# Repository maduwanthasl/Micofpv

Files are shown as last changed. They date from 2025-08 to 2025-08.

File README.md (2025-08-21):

# Custom 5" Freestyle FPV Build (Mark4 + DJI O4 Air Unit Pro)

**Type:** 5" freestyle • **FC/ESC:** SpeedyBee F405 V4 + 60A BLS 4-in-1 • **RX:** ExpressLRS 2.4G • **Video:** DJI O4 Air Unit Pro • **Props:** 5×3.3

**Demo video:** [Instagram Reel](https://www.instagram.com/reel/DLZa7YPyZ9yfRRH4GAgoWavU5bKhOaAaTe52I00/?igsh=MXVkb3AwZjJoZG41NA==)  
**Build photo:** [Image](https://github.com/maduwanthasl/Micofpv/blob/main/Images/fpv_image.jpg)

---

Freestyle FPV — Mark4 + O4

## Overview
I built this quad because I’m deeply interested in FPV and wanted a hobby freestyle rig that helps me unwind while delivering durable performance and clean HD video. In its current setup, it flies for about 5–6 minutes in freestyle, hovers at roughly 17% throttle, and weighs around 680 g (AUW with a 6S 1500 mAh pack). It also reaches an estimated top speed of about 150 km/h. What makes this build unique is a set of custom 3D-printed mounts that let the DJI O4 Air Unit Pro fit a Mark4 frame originally designed for the O3, plus simple printed feet for landing practice

### Features
The system uses DJI O4 digital video with iFlight ND filters, an ExpressLRS 2.4 G link for low-latency, long-range control, and clean wiring with a soft-mounted stack. For safety, the first power-up was done using a smoke stopper.

---

## Bill of Materials (BOM)

| Component | Quantity | Unit Price (LKR) | Total (LKR) |
|---|---:|---:|---:|
| dji o4 unit pro | 1 | 70,000 | 70,000 |
| dji goggles n3 | 1 | 68,000 | 68,000 |
| radio master pocket | 1 | 25,000 | 25,000 |
| kingston canvas go plus micro sd card | 2 | 3,500 | 7,000 |
| Iflight ND filters | 1 | 7,000 | 7,000 |
| mark4 5 inch frame | 1 | 6,000 | 6,000 |
| t- motor velox v2207 v3 1750 -4 | 2 | 16,000 | 32,000 |
| speedybee nano 2.4G express elrc receiver | 1 | 2,750 | 2,750 |
| speedybee F405 V4 BLS 60A FC & ESC | 1 | 21,000 | 21,000 |
| HQProp Ethix P3.3 5 inch propelers -4 | 6 | 1,000 | 6,000 |
| CNHL Black Series 1500mAh 22.2V 6S 100C Lipo Battery with XT60 Plug | 1 | 12,160 | 12,160 |
| VIFLY ShortSaver V2 - Smart Smoke Stopper × 1 | 1 | 6,400 | 6,400 |
| Iflight Transmitter Neck Strap × 1 | 1 | 2,240 | 2,240 |

**Grand Total: 265,550 LKR**

---

## Printed Parts (DJI O4 on Mark4)
- **Why:** O4 unit/mast spacing differs from O3-based mounts on the Mark4, so I designed **PLA+** brackets. (TPU is also an option for added vibration resistance.)  
- **Files:** see `3d-printed-parts/` (camera cage, rear mount, antenna bracket, landing feet).  
- **Install notes:** route O4 antennas clear of props, avoid sharp coax bends, and add zip-tie strain relief.

---

## Wiring & Assembly

### 4.1 Wiring Diagram
See **`wiring-diagram`** (O4 → FC, ESC → FC, ELRS → UART).

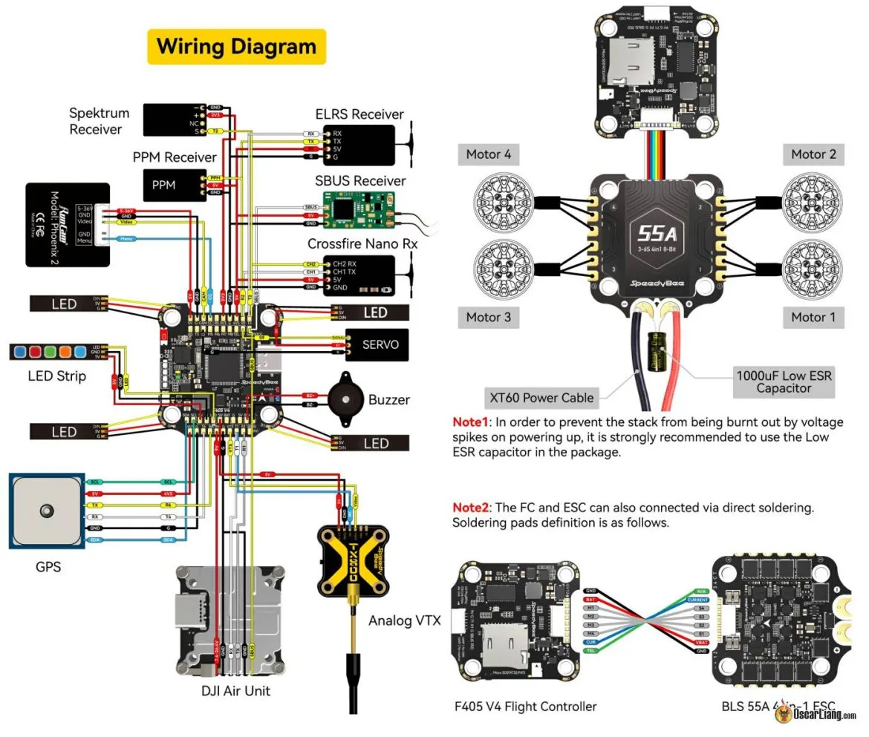
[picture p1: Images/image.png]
Wiring Diagram


### 4.2 UART Map
- **UARTx:** ExpressLRS
- **UARTy:** DJI O4 OSD

### 4.3 Assembly Steps
1. **Frame prep:** lightly sand carbon edges, add arm guards, install gummies.  
2. **Stack:** **ESC on bottom, FC on top** (or as your frame allows); add low-ESR cap across main leads.  
3. **Motors:** tin leads, route cleanly, and confirm phases reach correct ESC pads.  
4. **Receiver:** wire ELRS to 5 V/GND/TX/RX (no inversion); keep bind button accessible.  
5. **O4 unit:** mount 3D-printed parts, connect power/ground/UART, and manage antenna coax carefully.  
6. **Final checks:** continuity test → smoke stopper power-up (props **off**) → motor direction test → failsafe test.

---

## Firmware & Configuration
- **Flight Controller:** Betaflight `4.5` (SpeedyBee F405 V4 target).  
- **Receiver:** ExpressLRS 2.4G (manual bind).  
- **DJI O4 & Goggles:** pair, set recording options/bitrate; enable OSD/Canvas Mode if used.

### 5.1 Betaflight Basics
- **Receiver tab:** **Serial-based receiver (CRSF)**.  
- **Modes:** Arm, Angle/Horizon (optional), Beeper (DShot).  
- **Motor idle:** ~5–6% (freestyle starting point).

### 5.2 ExpressLRS
- Match **channel map** to the radio; confirm endpoints and RSSI/Link Quality.

### 5.3 O4 Video
- Typical recording: **4K/60** (RockSteady optional).  
- Choose **ND filter** based on lighting to reduce jello and maintain shutter speed.

---

## Simulator Practice
- **Path:** started on **SkyDrive**, then moved to **Liftoff** (worth buying after basics).  
- **Goal:** stick discipline and rate matching **before** maiden.  
- **Notes:** transmitter setup and endpoint calibration to match Betaflight.

---

## Testing & Safety
- Pre-power continuity → **smoke-stopper** → USB setup with props off.  
- Motor test + direction swap in Betaflight.  
- Failsafe check (radio off).  
- First hover checklist; LiPo storage/charging safety (6S).

---

## Performance (current)
- **Typical flight time:** 5–6 min (freestyle)  
- **Hover throttle:** ~17%  
- **Weight:** ~680 g (AUW with 6S 1500 mAh)

---

## Future Work
- GPS + Rescue, beeper, LEDs, GoPro mount, better battery pad, further tune refinements.

---

## Acknowledgments
Tutorials and references I followed:
- [Rogue FPV Build Series](https://www.youtube.com/watch?v=zWR0B7xqwMg&list=PLgRKeXqwf6Q2vFpVJjNjZdjeIQmNUhvDn&ab_channel=RogueFPV)  
- [Joshua Bardwell — 5″ Build Guide](https://www.youtube.com/watch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)  
- [ELRS Setup](https://youtu.be/XB6b0HrDGeA?si=0KDyoqJ684y_nBzz)  
- [Betaflight Beginner Setup](https://youtu.be/zj90LK8XR68?si=Ff384E5LzpYpau6v)  
- [ESC & Motor Direction](https://youtu.be/-jT_25XurcM?si=VqhFGBFgVTrHDFWf)  
- [DJI O4 Tips](https://youtu.be/xZ465T5B0Ls?si=CluL7JrLkbhmzXJg)  
- [General Troubleshooting](https://youtu.be/mhkMIsVJD4c?si=JrtRLWs-BKeLUrqn)

Community presets & docs were also super helpful—thanks!

---

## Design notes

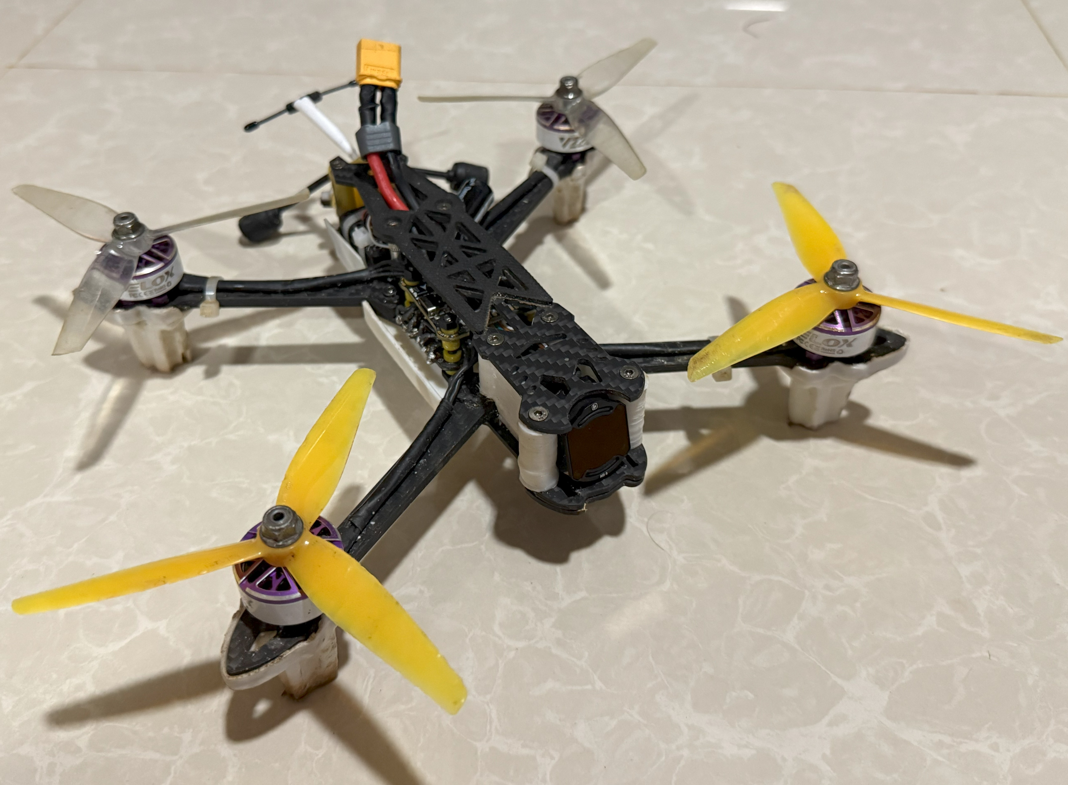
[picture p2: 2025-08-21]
Images/fpv_image.jpg

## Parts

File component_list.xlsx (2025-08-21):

Custom FPV Build - Component List
Component | Quantity | Unit Price(LKR) | Total Price(LKR)
dji o4 unit pro | 1 | 70000 | 70000
dji goggles n3 | 1 | 68000 | 68000
radio master pocket | 1 | 25000 | 25000
kingston canvas go plus micro sd card | 2 | 3500 | 7000
Iflight ND filters | 1 | 7000 | 7000
mark4 5 inch frame | 1 | 6000 | 6000
t- motor velox v2207 v3 1750 -4 | 2 | 16000 | 32000
speedybee nano 2.4G express elrc receiver | 1 | 2750 | 2750
speedybee F405 V4 BLS 60A FC & ESC | 1 | 21000 | 21000
HQProp Ethix P3.3 5 inch propelers -4 | 6 | 1000 | 6000
CNHL Black Series 1500mAh 22.2V 6S 100C Lipo Battery with XT60 Plug | 1 | 12160 | 12160
VIFLY ShortSaver V2 - Smart Smoke Stopper × 1 | 1 | 6400 | 6400
Iflight Transmitter Neck Strap × 1 | 1 | 2240 | 2240
Sum |  |  | 265550

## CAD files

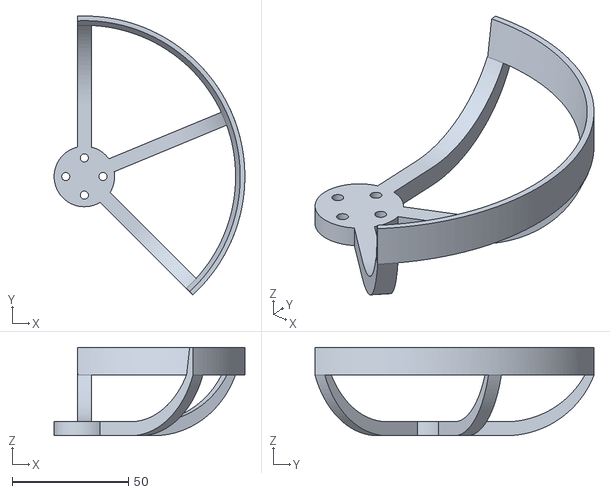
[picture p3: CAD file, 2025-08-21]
3d printed parts/3d printed parts/prop_guard_x1_mirror.stl
82.0 x 119.9 x 38.0

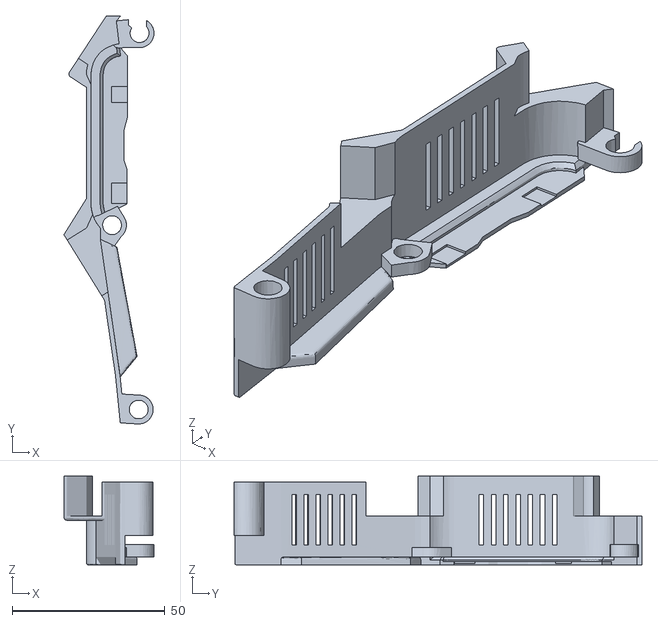
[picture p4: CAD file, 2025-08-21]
3d printed parts/3d printed parts/Powerful Tumelo-Maimu.stl
29.5 x 133.6 x 29.0

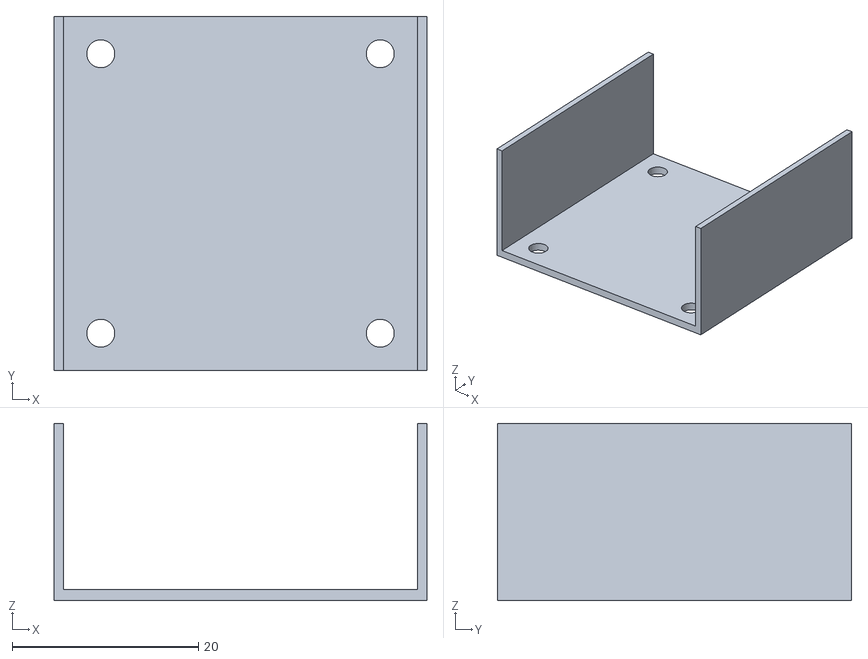
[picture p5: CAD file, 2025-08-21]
3d printed parts/3d printed parts/fpv_vtx_side_cover.STL
40.0 x 38.0 x 19.0

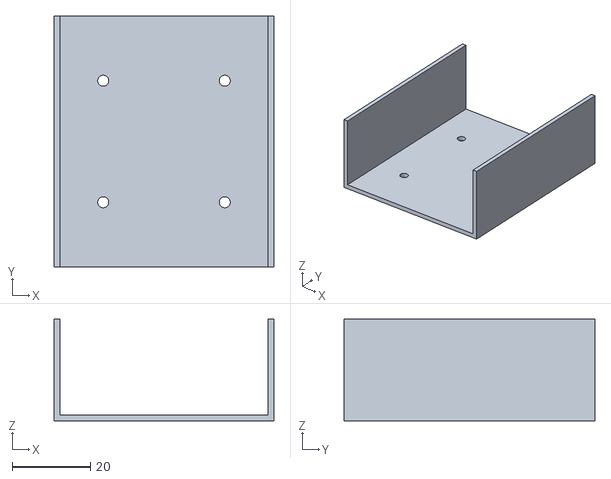
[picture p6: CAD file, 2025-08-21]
3d printed parts/3d printed parts/esc_fc_gaurd.STL
56.0 x 64.0 x 26.0

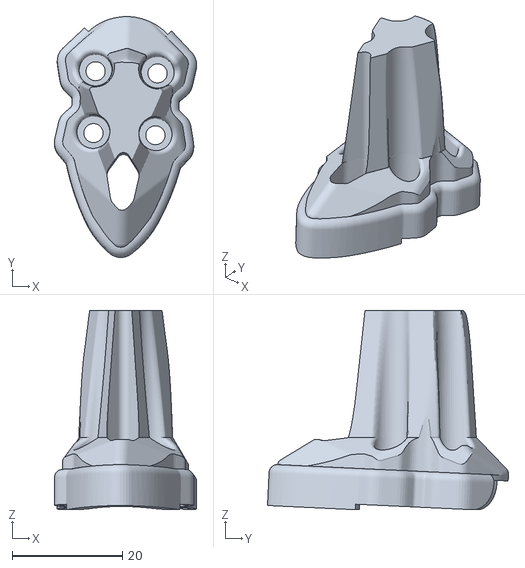
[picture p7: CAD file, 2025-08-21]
3d printed parts/3d printed parts/mark4 landing gaurd.stl
25.8 x 43.7 x 36.2

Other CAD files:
3d printed parts/3d printed parts/Powerful Tumelo-Maimu (1).stl
